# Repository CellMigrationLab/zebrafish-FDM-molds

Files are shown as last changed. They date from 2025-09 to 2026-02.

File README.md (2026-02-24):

# Customizable FDM 3D-printed zebrafish embryo molds for live imaging

---

## Introduction

This repository provides design files, printing instructions, and documentation for 3D-printed molds for orienting zebrafish embryos. The molds are designed to ensure dorsal positioning of embryos during live imaging  between 50 hours post-fertilization (hpf) and 5 days post-fertilization (dpf).

Unlike previously published molds fabricated with stereolithography (SLA)–based 3D printing (e.g., Geng & Peterson, 2021; Kleinhans & Lecaudey, 2019; Miller et al., 2025; Wittbrodt et al., 2014), our approach uses fused deposition modeling (FDM). Both SLA and FDM are part of the broader category of additive manufacturing, in which objects are built up layer by layer rather than removed from a solid block (subtractive manufacturing) or formed in a mold (injection molding).

* SLA printing relies on a laser or UV light to cure liquid resin layer by layer, producing parts with very fine resolution and smooth surfaces.
* FDM printing extrudes melted thermoplastic filament (such as PLA) through a heated nozzle to build up layers, making it widely accessible and cost-effective, but with lower resolution.

Because of these differences, SLA prints can reproduce the sharp triangular cavities of the CAD design, while FDM prints approximate them with rectangular cavities due to nozzle width (**Figure 1A** vs **1B**). Nevertheless, the molds (**Figure 2**) remain highly effective for stabilizing zebrafish embryos, while being affordable and easy to reproduce in most laboratory settings.

If you want to update the design, check the [how-to/](how-to/README.md) folder.

---

## 📂 Repository contents

* `README.md file`
* Description of tool
* How to print and assemble
* How to redesign

* `design_files/`
* `stl/` → ready-to-print STL files
* `f3d/` → Fusion 360 editable files
* `step/` → STEP files for CAD interoperability

* `printing/`
* `gcode/` → tested gcode files for 3D printers
* `slicer_profiles/` → PrusaSlicer config (.3mf / .ini)
* `printing_settings.md` → detailed printing settings

* `docs/`
* `zebrafish-molds-application-note.pdf`
* `figures/`

* `LICENSE`

---
## Figures

<p align="center">
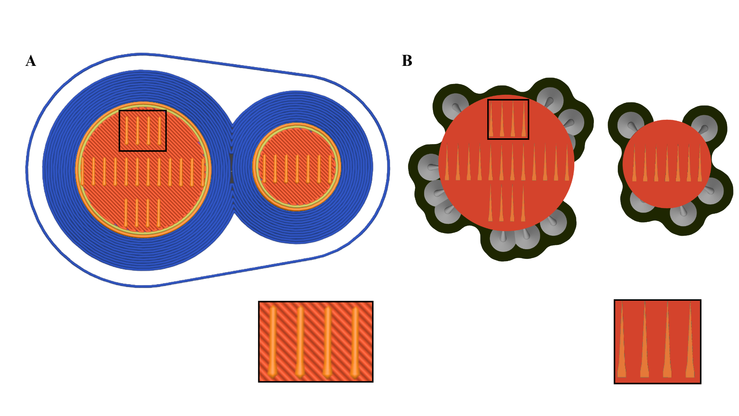
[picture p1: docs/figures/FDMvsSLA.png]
FDM vs SLA printing comparison

</p>

**Figure 1.** Differences, through g-code preview, in mold slots between FDM (**A**) and SLA (**B**) printing.

---

<p align="center">
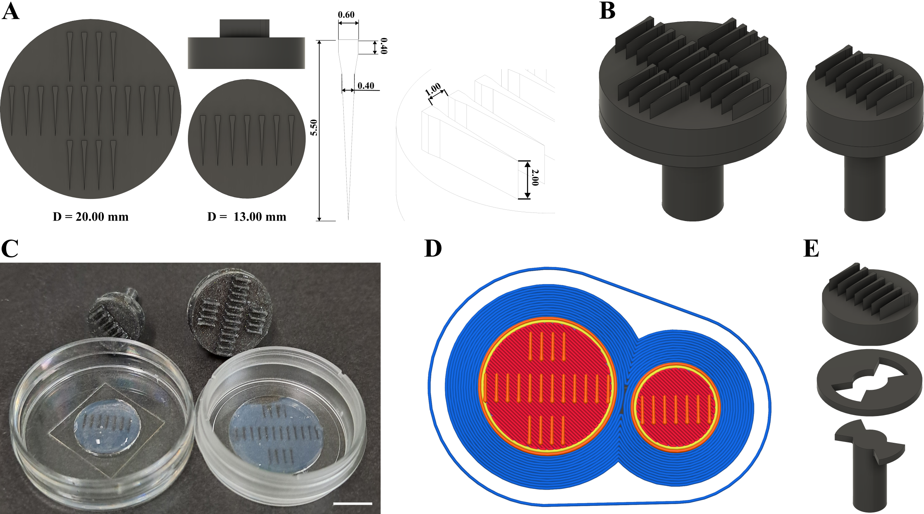
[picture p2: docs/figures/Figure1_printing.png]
Zebrafish molds 3D designs

</p>

**Figure 2.** FDM-printing-based mold design improves live in vivo imaging of brain vascularization in developing zebrafish embryos.
(**A**) CAD renderings of two circular mold sizes (20 mm and 13 mm) with slot dimensions in millimeters. Each slot measures 0.40 mm wide at the narrowest point, 0.60 mm at the widest, and extends 5.50 mm deep; the spacing between slots is 1.00 mm, and the slot height above the base is 2.00 mm. The smaller mold was designed for use with 14 mm coverslips, while the larger one was tested with 21 mm coverslips. The mold design was kept circular rather than rectangular to fit tightly within the well and stay level. Design files for both sizes are available for download via the associated GitHub repository.
(**B**) Perspective views of the assembled molds.
(**C**) Wells in 1.5% low-melting-point agarose were made using the seven- and twenty-tooth molds in 14- and 21-mm glass-bottom dishes, respectively.
(**D**) PrusaSlicer g-code preview illustrating how FDM resolution (0.4 mm nozzle) converts triangular cavities into rectangular slots.
(**E**) Exploded view of mold components, with a removable handle to facilitate positioning in small dishes.

---

<p align="center">
Zebrafish molds 3D designs
</p>

**Figure 3.** FDM-printing-based mold design enables consistent live imaging of microglia motility and brain vascularization in developing zebrafish larvae.
(**A**) Top left: image showing empty agarose wells created using the seven-teeth mold. Bottom left: image showing 56 hpf *Tg(fli1a:GFP-CAAX)*; *Tg(gata1a:DsRed)* larvae inserted into the wells. The black-dotted box indicates the area magnified in the next panel. Right: magnified area of mounted larvae. Live brightfield imaging of the middle larvae, marked with an orange box, is presented in **panel G**. Scale bars: left panels 1 mm, right panel 500 µm.
(**B**) Brightfield midplane-volume image of the 56hpf *Tg(fli1a:GFP-CAAX)*; *Tg(gata1a:DsRed)* larvae from **panel F** (orange boxed region), before the start of time-lapse acquisition, shown in **panels H-I**, orange box. Scale bar: 50 µm.
(**C**) Maximum intensity projection of horizontal sections from overnight time-lapse imaging of vasculature, *Tg(fli1a:GFP-CAAX)* (cyan), and erythrocytes, *Tg(gata1a:DsRed)* (red), in the developing brain of the mounted larvae (identical to those shown in **panels F-G**, orange box). The first timepoint is shown in **panel (i)**. Temporal color coding of the *fli1:GFP* signal over the acquisition (time-lapse, 20-minute imaging interval, 32 time points) **(ii)**. The color bar indicates the transition from time point 1 (magenta) to 32 (bright yellow). See also Movie S1. Scale bars: 50 µm.
(**D**) High-magnification (63x) imaging of the brain vascularization process. The maximum intensity projection of the first acquisition time point is shown in **(i)**. The magnified area (indicated with an orange rectangle) shows filopodia-like protrusions extending from the *fli1:GFP*-positive (cyan) endothelial tip cell **(ii)**. The *gata1a:DsRed* positive erythrocytes (red) inside a more mature blood vessel are also shown. See also Movie S1. Scale bars: 25 µm and 5 µm, respectively.
(**E**) Temporal color coding of microglia dynamics in *Tg(mpeg1.1:GFP-CAAX)* 72 hpf larvae, over the acquisition period (10-minute imaging interval, 80 time points). The color bar indicates the transition from time point 1 (magenta) to 80 (bright yellow). Scale bar: 50 µm.
(**F**) Selected time-points from **panel E** (blue box),  showing microglia *Tg(mpeg1:GFP-CAAX)* (grey) migration and process elongation. Scale bar: 20 µm.

---

<p align="center">
Supplementary movie
</p>

**Supplementary Movie S1.** Movie S1. Brain vascularization in the developing brain of a mounted larva. Development of brain vasculature and erythrocyte flow in more mature vessels was imaged in larvae expressing both *Tg(fli1a:GFP-CAAX)* (cyan) and *Tg(gata1a:DsRed)* (red) reporters. For **parts A** and **B**, the time intervals are 20 and 2 minutes, and the scale bars are 40 µm and 20 µm, respectively. For **part A**, acquisition was started at 54 hpf, and for **part B**, at 68 hpf (in the same larvae).

---

<p align="center">
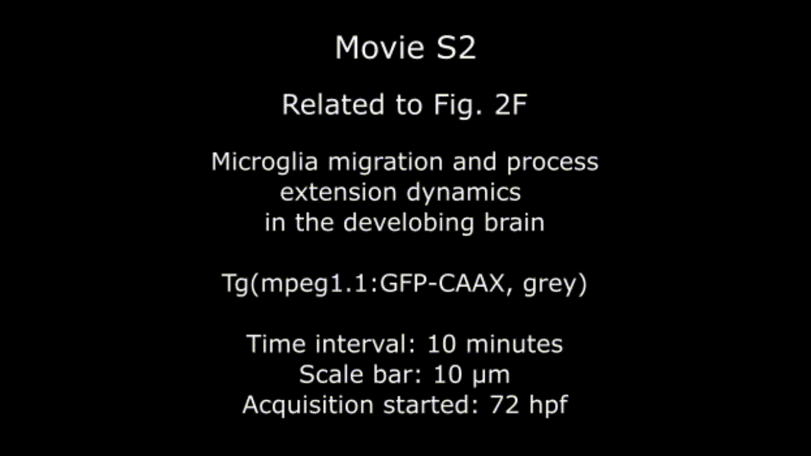
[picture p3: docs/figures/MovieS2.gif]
Supplementary movie

</p>

**Supplementary Movie S2.** Microglia migration and process extension dynamics in the developing brain of a mounted larva. Single microglia migration and elongation and retraction of its processes, labelled by *Tg(fmpeg1.1:GFP-CAAX)* (grey) reporter, was imaged for 12 hours. Time interval 10 minutes. Acquisition started at 72 hpf.  Scale bar 10  µm.

---

## 🔍 Design considerations

* **Circular footprint**: Chosen to fit tightly into 14 mm and 21 mm coverslip dishes.
* **FDM vs SLA**: FDM printing with a 0.4 mm nozzle limits precision, resulting in rectangular cavities instead of sharp triangular ones. Functionality is unaffected, but geometric fidelity is reduced.
* **Stage compatibility**: Optimized for zebrafish between 50 hpf–5 dpf.
* **Accessibility**: All files are openly shared for reproduction and adaptation.

⚠️ **Note:** Embryos younger than 50 hpf are too small for this design. Separate molds with smaller wells would be required. (see the [how-to/](how-to/README.md) folder).

## 📚 References

* Geng, Y., & Peterson, R. T. (2021). Rapid Mounting of Zebrafish Larvae for Brain Imaging. Zebrafish, 18(6), 376. https://doi.org/10.1089/zeb.2021.0062
* Kleinhans, D. S., & Lecaudey, V. (2019). Standardized mounting method of (zebrafish) embryos using a 3D-printed stamp for high-content, semi-automated confocal imaging. BMC Biotechnology, 19(1), 68. https://doi.org/10.1186/s12896-019-0558-y
* Miller, J. C., Koirala, P., Torre, M. F. A. de la, Farsi, M., Lieberth, J., Shrestha, R., & Bloomekatz, J. (2025). Custom 3D-Printed Molds for Zebrafish Imaging and Cardiac Development. Journal of Visualized Experiments (JoVE), 222, e68768. https://doi.org/10.3791/68768
* Wittbrodt, J. N., Liebel, U., & Gehrig, J. (2014). Generation of orientation tools for automated zebrafish screening assays using desktop 3D printing. BMC Biotechnology, 14(1), 36. https://doi.org/10.1186/1472-6750-14-36

---

## 📖 Citation

If you use these zebrafish molds in your research, please cite:

**Customizable FDM-based zebrafish embryo mold for live imaging** Rivera Pineda MX, Lehtimäki J, Jacquemet G.

*bioRxiv* (2025)
[](https://doi.org/10.1101/2025.11.24.689779)

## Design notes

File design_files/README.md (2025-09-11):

# Design files for zebrafish embryo molds

This directory contains all CAD and related files for the FDM-printed zebrafish embryo orientation molds.  
Different file formats are provided to support a range of use cases, from direct printing to full CAD editing.

## 📂 Subfolders
- **`stl/`** → Ready-to-print mesh files for 3D printing.  
- **`f3d/`** → Editable Fusion 360 project files with parametric history.  
- **`step/`** → Cross-CAD geometry files for SolidWorks, FreeCAD, Onshape, etc.  
- **`drawings/`** → 2D technical drawings with dimensions and component breakdowns.

## 🛠 Choosing the right file
- Use .stl if you just want to slice and print.  
- Use .f3d if you want to make design modifications in Fusion 360.  
- Use .step if you need to work in a different CAD program.  
- Use drawings if you only need dimensions or want to check geometry without CAD software.

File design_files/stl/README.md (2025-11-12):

# STL Files (`.stl`)

This folder contains the STL files for the zebrafish embryo molds. STL files describe the mesh geometry of the model and are the most common format for 3D printing. 

## Files
- **`zfish-mold-stamp/stemlock/stem-D13.stl`** → Mold with 13 mm diameter, designed for 14 mm coverslip plates.  
- **`zfish-mold-stamp/stemlock/stem-D20.stl`** → Mold with 20 mm diameter, tested with 21 mm coverslip plates.  

## Notes
- STL files are ready-to-slice in PrusaSlicer, Cura, or other slicers.  
- Unlike `.f3d` or `.step` files, STLs do not include parametric history or editable sketches. They are mesh-only files intended for printing.  
- To modify geometry (e.g., slot width, spacing, or mold diameter), use the editable `.f3d` (Fusion 360) or `.step` files instead.  
- Both STL versions share the same slot dimensions:  
  - Slot depth: **5.50 mm**  
  - Narrow width: **0.40 mm**  
  - Wide width: **0.60 mm**  
  - Slot spacing: **1.00 mm**  
  - Slot height above base: **2.00 mm**  

## Recommended workflow
1. Choose the STL that matches your imaging dish (13 mm or 20 mm).  
2. Open in PrusaSlicer (or another slicer).  
3. Apply the provided print settings (`printing/printing_settings.md` or `.ini`/`.3mf` profile).  
4. Export G-code and print.

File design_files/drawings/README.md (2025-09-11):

# Technical drawings

This folder contains 2D technical drawings of the zebrafish embryo molds. These provide a quick reference for dimensions and part relationships without requiring CAD software.

## Files
- **`zfish-mold-D13_drawing.pdf`** → Drawing of the 13 mm mold (for 14 mm coverslip plates).  
- **`zfish-mold-D20_drawing.pdf`** → Drawing of the 20 mm mold (for 21 mm coverslip plates).  

## Contents
Each drawing includes:
- Overall mold dimensions (diameter, height, slot spacing).  
- Individual component views:  
  - Stamp (slot pattern and depth).  
  - Stemlock (circular locking ring).  
  - Stem (removable handle).  
- Exploded views of how components fit together.   

## Notes
- Scale in drawings: 3:1  
- Units: millimeters (mm)  
- If modifications are desired, consult the `.f3d` or `.step` files in their respective folders.

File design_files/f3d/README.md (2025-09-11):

# Fusion 360 source files (`.f3d`)

This folder contains the editable Fusion 360 project files for the zebrafish embryo molds. These preserve the parametric history, allowing users to modify slot dimensions, mold diameter, or handle design directly in Fusion 360.

## Files
- **`zfish-mold-D13.f3d`** → Mold with 13 mm diameter, designed for 14 mm coverslip plates.  
- **`zfish-mold-D20.f3d`** → Mold with 20 mm diameter, tested with 21 mm coverslip plates.  

## Dimensions (shared by both designs)
- Slot depth: **5.50 mm**  
- Slot narrow width: **0.40 mm**  
- Slot wide width: **0.60 mm**  
- Slot spacing: **1.00 mm**  
- Slot height above base: **2.00 mm**  

## Notes
- Files open in Autodesk Fusion 360 (educational or commercial license).  
- The design is structured into components (stamp:mold; stemlock:base; stem:handle) for easier editing.  
- Use these if you wish to customize geometry (e.g., for different embryo stages or dish sizes).

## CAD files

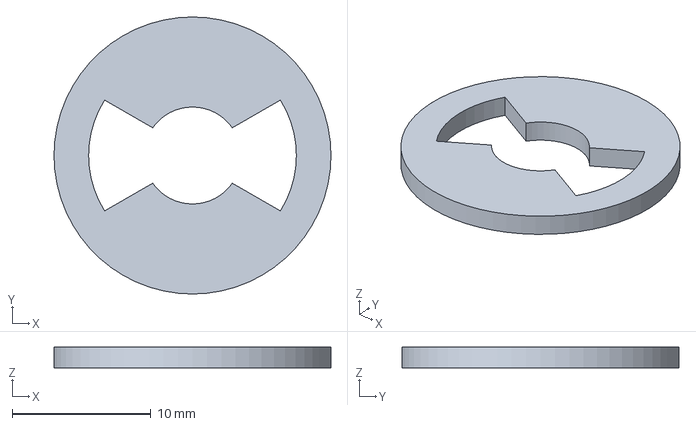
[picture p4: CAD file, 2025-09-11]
design_files/step/zfish-mold-stemlock-D20.step
20.0 x 20.0 x 1.50 mm

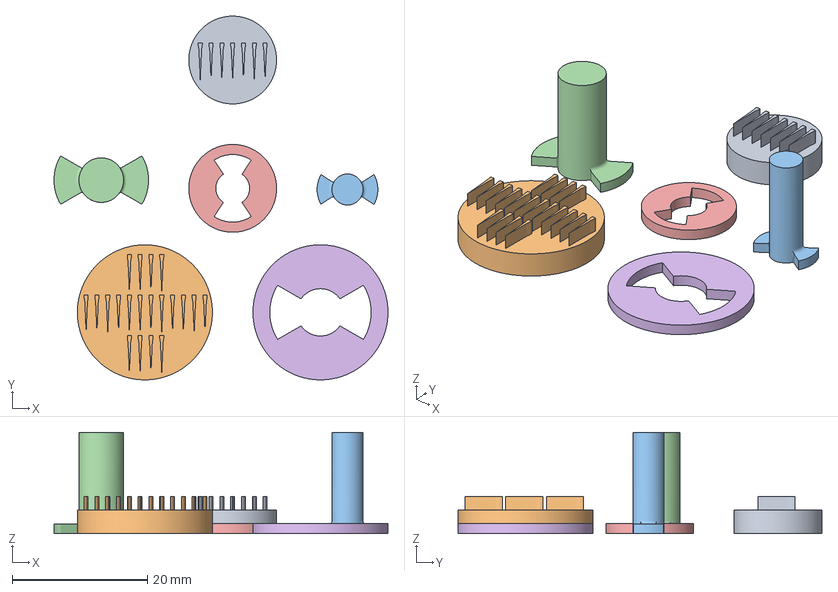
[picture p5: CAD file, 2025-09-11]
printing/slicer_profiles/zfish-molds-print-settings.3mf
49.5 x 53.9 x 15.0 mm
zfish-mold-stamp-D13
zfish-mold-stamp-D20
zfish-mold-stem-D13
zfish-mold-stem-D20
zfish-mold-stemlock-D13
zfish-mold-stemlock-D20

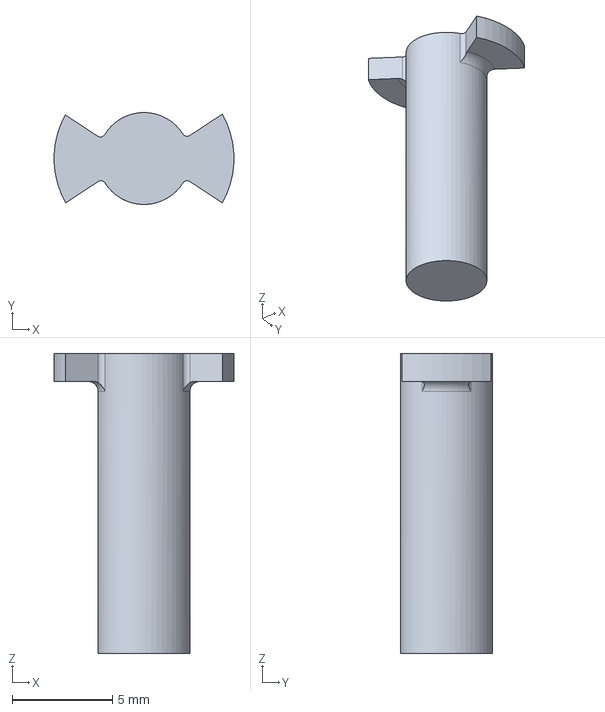
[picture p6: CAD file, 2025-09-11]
design_files/step/zfish-mold-stem-D13.step
8.99 x 4.60 x 15.0 mm

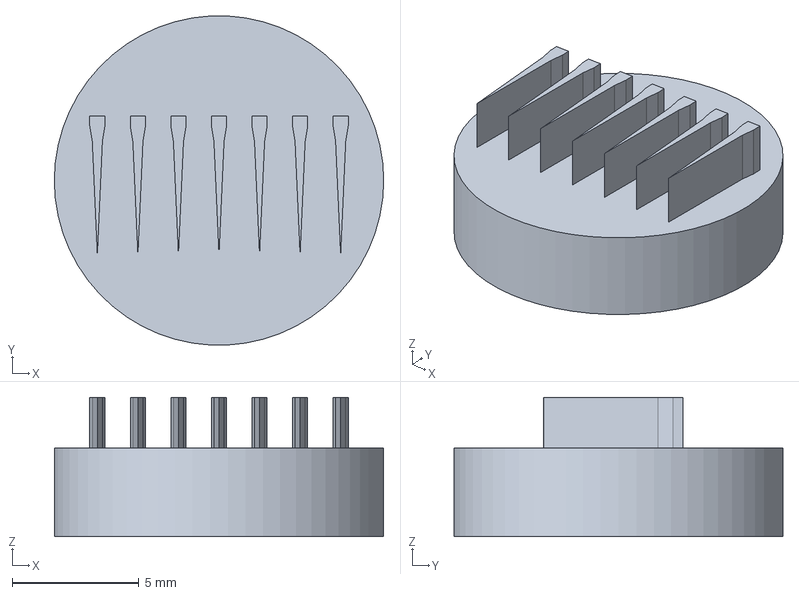
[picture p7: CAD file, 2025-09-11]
design_files/step/zfish-mold-stamp-D13.step
13.0 x 13.0 x 5.50 mm

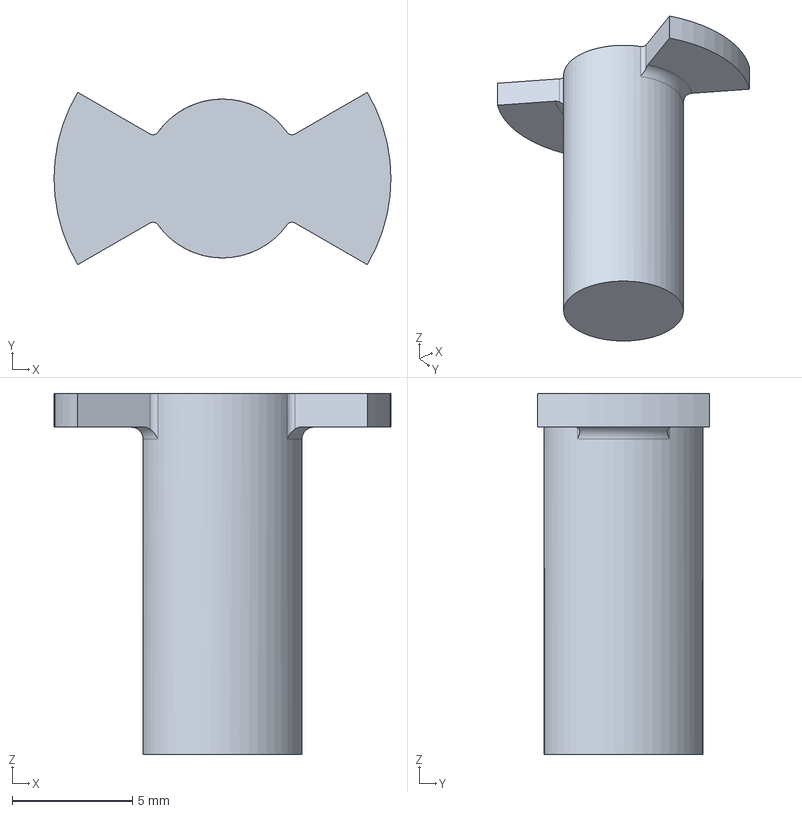
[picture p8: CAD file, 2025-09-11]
design_files/step/zfish-mold-stem-D20.step
14.0 x 7.16 x 15.0 mm

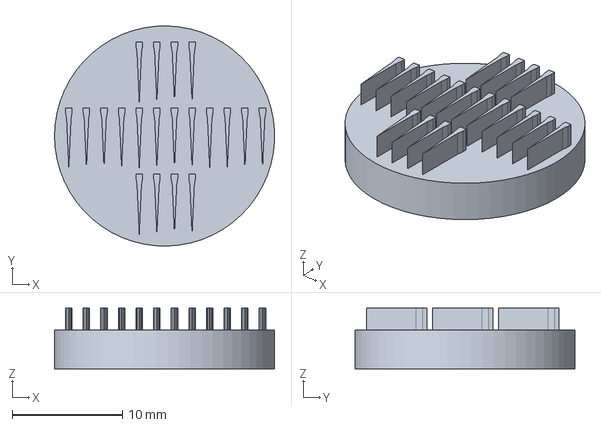
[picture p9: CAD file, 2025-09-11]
design_files/step/zfish-mold-stamp-D20.step
20.0 x 20.0 x 5.50 mm

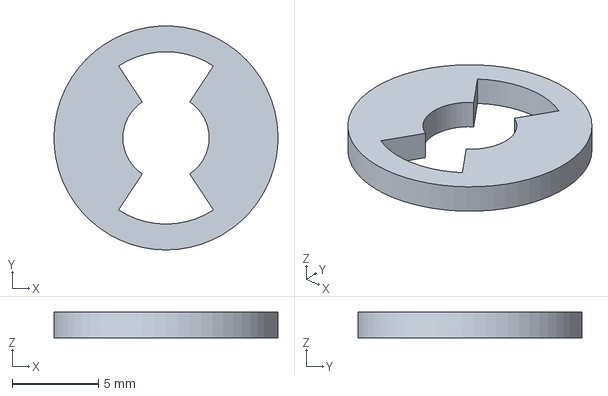
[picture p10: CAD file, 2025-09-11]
design_files/step/zfish-mold-stemlock-D13.step
13.0 x 13.0 x 1.50 mm

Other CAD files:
design_files/f3d/zfish-mold-D13.f3d
design_files/f3d/zfish-mold-D20.f3d
design_files/stl/zfish-mold-stamp-D13.stl
design_files/stl/zfish-mold-stamp-D20.stl
design_files/stl/zfish-mold-stem-D13.stl
design_files/stl/zfish-mold-stem-D20.stl
design_files/stl/zfish-mold-stemlock-D13.stl
design_files/stl/zfish-mold-stemlock-D20.stl

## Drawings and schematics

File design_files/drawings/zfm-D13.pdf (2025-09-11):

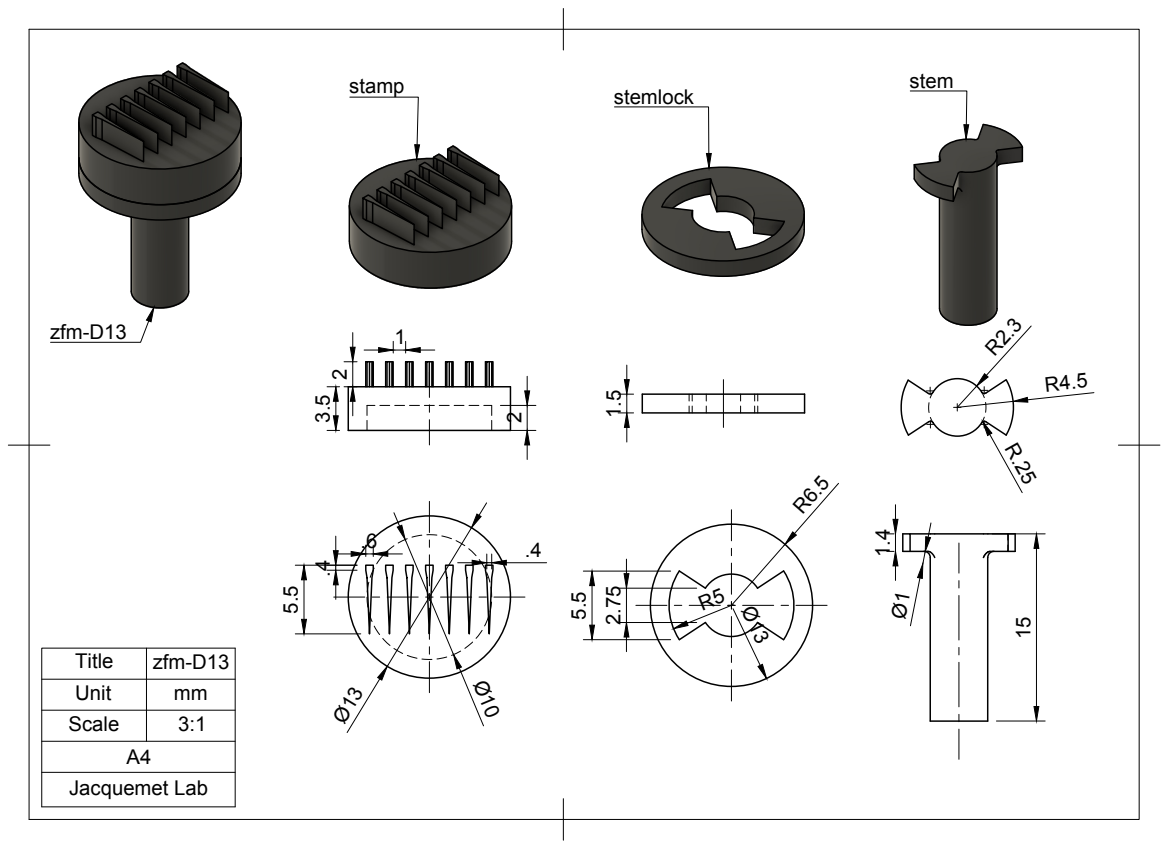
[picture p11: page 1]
Jacquemet Lab

Title | zfm-D13
Unit | mm
Scale | 3:1

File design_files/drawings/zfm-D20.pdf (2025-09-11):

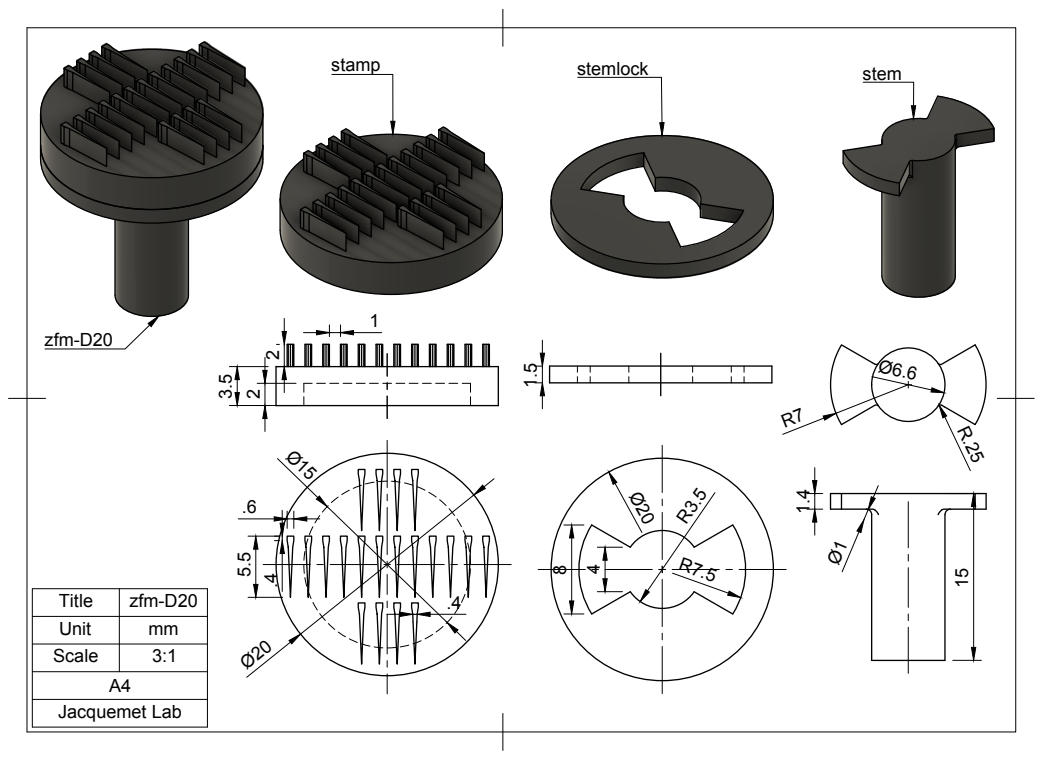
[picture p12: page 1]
Jacquemet Lab; stamp; stemlock; stem 3.5 2

Unit | mm
Scale | 3:1

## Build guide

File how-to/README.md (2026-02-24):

# How-to guides

This directory contains how-to guides related to the FDM-printed zebrafish embryo orientation molds.  

## 📂 Content
- **how-to 1: redesign the wells** → Modify the molds according to the developmental stage of your zebrafish embryos/larvae.
- **how-to 2: print and assemble** → Print and assemble your molds.

## How-to 1: Redesign the wells

***Note 1:*** Changing one dimension of the first well propagates to the others. Therefore, after edits, you should always check for overlapping and spacing. 
***Note 2:*** These steps can be implemented to modify other dimensions of the mold, such as the depth of the wells or the diameter of the mold.
***Note 3:*** All redesign steps were performed in Autodesk Fusion 360. Although Fusion 360 is subscription-based, a free educational license is available for academic users.

Steps:
1. Open the corresponding mold file (.f3d file) in Fusion 360. Open the wells sketch by double-clicking the first sketch in the Timeline (highlighted by the red rectangle in Figure 3A).
2. Modify well dimensions by double-clicking the desired dimension as shown in Figure 3B (red rectangle). Edit the relevant dimensions (head width, neck width, length) according to the embryo/larva stage. See Figure 3E for suggested dimensions based on embryo stage (based on Kimmel et al. (1995)).
3. After resizing the wells, check the dimensions regarding the distance between the first well and the edge reference. Update it so the modified wells still fit cleanly within the diameter boundary. E.g.: 1.4 mm (Figure 3B, red triangle) to 1.2 mm (Figure 3C, red triangle) after changing the well geometry.
4. Verify spacing and pattern integrity by ensuring that the wells don’t overlap after the update. If the wells overlap, modify the spacing by zooming in, double-clicking the Rectangular Pattern Constraint (dotted rectangle in Figure 3D), and adjusting the number of wells (green triangle in Figure 3D) and the distance between them (magenta triangle in Figure 3D).
5. Click Finish Sketch. In the Timeline, confirm that the extrude and cut features regenerated correctly.
6. Export the updated mold as an STL file and proceed to slicing and 3D printing. To export, go to File> Export…, and change the Type to STL Files (*.stl).

<p align="center">
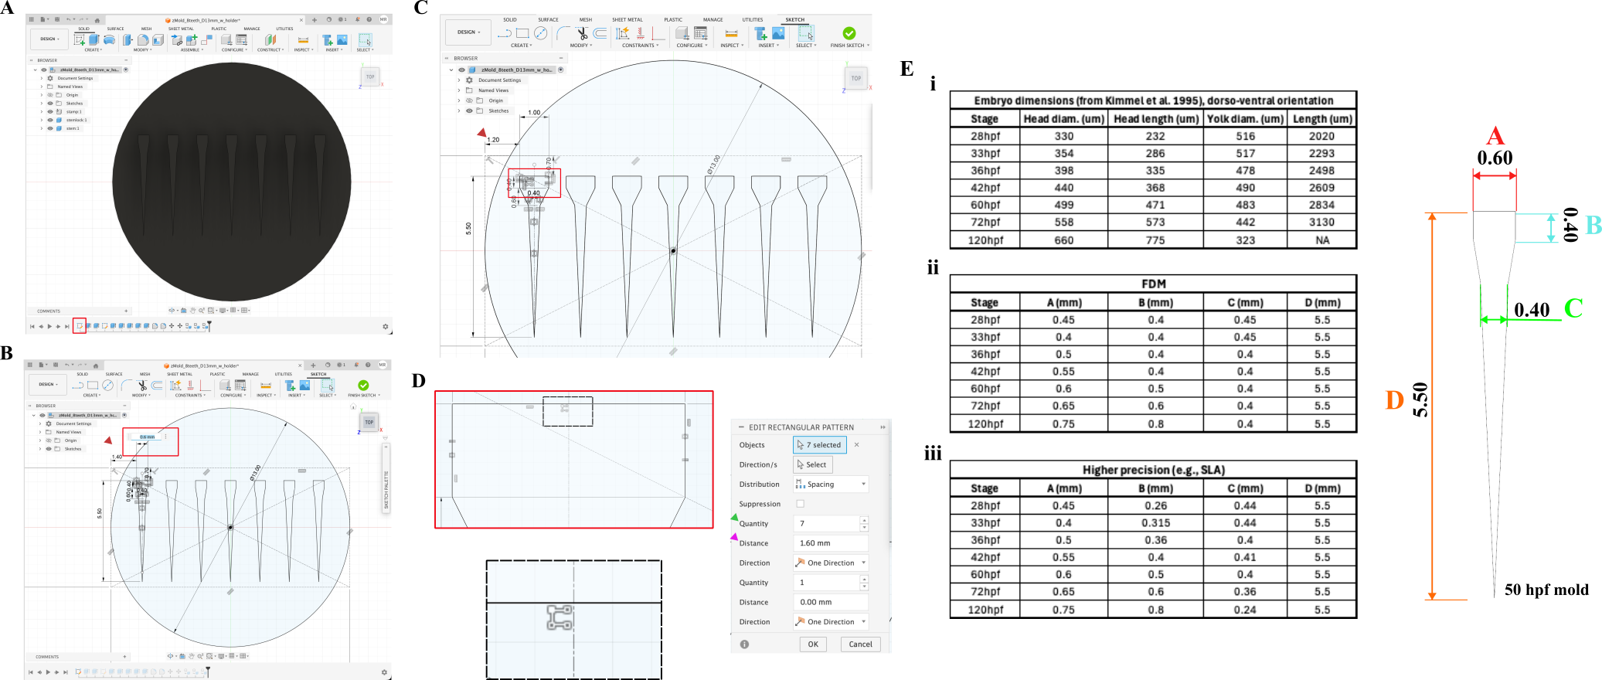
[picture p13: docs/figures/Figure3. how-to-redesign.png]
how to redesign the zebrafish molds

</p>

**Figure 1.** How to redesign the zebrafish molds. 
(**A**) Autodesk Fusion 360 project file showing the mold with replicated wells arranged to fit a standard glass-bottom imaging dish. The red rectangle highlights the sketch to edit to modify the wells’ dimensions.
(**B**–**C**) The well sketch can be edited by opening the first sketch in the Timeline and modifying the parameterized dimensions (example shown for the first well; red rectangle). After resizing, the offset between the first well and the dish boundary should be updated to ensure the pattern remains within the circular mold footprint (red triangle). 
(**D**) If resizing causes wells to overlap, spacing and/or the number of wells can be adjusted using the Rectangular Pattern Constraint (dotted black rectangle). 
(**E**) Suggested stage-dependent dimensions to guide redesign: (**E**, i) embryo measurements (dorso-ventral orientation) extracted from Kimmel et al. (1995); (**E**, ii) corresponding recommended well parameters for FDM printing; (**E**, iii) corresponding parameters for higher-precision printing (e.g., SLA). Right: schematic of the well geometry indicating the editable parameters **A**-**D** (mm) used throughout the tables.

---

## 🖨 How-to 2: Printing and assembly instructions

1. Download STL files from `design_files/stl/`.
2. Open in PrusaSlicer (or your slicer of choice).  
   - Recommended settings are included in `printing/printing_settings.md`.
3. Print using PLA material with a 0.4 mm nozzle.  
4. ⚠️ Critical step.  To minimize adhesion to the agarose gel, sand the printed molds carefully but roughly. This will increase surface porosity for resin infiltration (next step). 
5. Apply a thin coat of two-part epoxy over all surfaces of the mold that contact the agarose gel to create a smooth, sealed surface. Allow to cure fully before use (24h or as required by the manufacturer).
6. The stamp component is glued to the middle ring, forming a single object and creating an internal pocket. 
7. The stem is inserted into this pocket and rotated ~180° to lock or unlock its position. Once assembled, the mold is ready for use.

<p align="center">
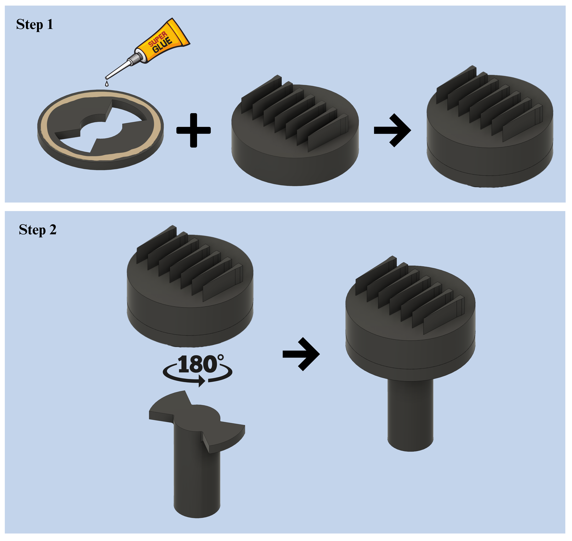
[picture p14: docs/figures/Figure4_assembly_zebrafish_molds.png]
zebrafish mold assembly steps

</p>

**Figure 2.** Assembly of the zebrafish molds.

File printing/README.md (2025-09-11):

### 🖨 Profiles and settings

This repository provides multiple ways to reproduce the validated printing parameters:

- **`printing_settings.md`** → A human-readable summary of all printing settings (layer height, infill, speeds, cooling, supports, etc.). These values can be entered manually into any slicer (e.g., Cura, Simplify3D, etc.).  
- **`zfish-molds-print-settings.ini`** → A PrusaSlicer-specific profile. This format is inherent to PrusaSlicer and may not be directly compatible with other slicers.  
- **`zfish-molds-print-settings.3mf`** → A PrusaSlicer project profile that can be dragged and dropped into PrusaSlicer for one-click setup.

👉 If you are **not using PrusaSlicer**, refer to `printing_settings.md` for the full parameter set.

👉 May require adjustment for other printers/materials.

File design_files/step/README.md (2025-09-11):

# STEP files (`.step`)

This folder contains STEP versions of the zebrafish embryo mold designs. STEP is a widely supported neutral CAD format and can be imported into software such as SolidWorks, FreeCAD, Onshape, Rhino, or CATIA.

## Files
- **`zfish-mold-stamp/stemlock/stem-D13.step`** → Mold with 13 mm diameter, designed for 14 mm coverslip plates.  
- **`zfish-mold-stamp/stemlock/stem-D20.step`** → Mold with 20 mm diameter, tested with 21 mm coverslip plates.  

## Notes
- STEP files preserve geometry, but do not include the parametric history or design tree from Fusion 360.  
- Best used if you want to view or adapt the model in a non-Fusion CAD environment.  
- For fully editable parametric designs, use the `.f3d` files in the `f3d/` folder.

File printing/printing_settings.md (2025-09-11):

# Printing settings for zebrafish molds

These settings were generated and validated in PrusaSlicer 2.8.1 for an Original Prusa i3 MK3S/MK3S+ printer using Prusament PLA (1.75 mm, Jet Black). May require adjustment for other printers/materials.

---

## General
- **Printer technology:** FDM (FFF)
- **Printer model:** Prusa i3 MK3S/MK3S+
- **Nozzle diameter:** 0.4 mm
- **Layer height:** 0.10 mm (high-detail setting)
- **Extrusion width:** 0.45 mm

---

## Temperatures
- **Nozzle temperature:** 215 °C (first layer and subsequent layers)
- **Bed temperature:** 60 °C (first layer and subsequent layers)

---

## Speeds
- **Perimeters:** 30 mm/s  
- **External perimeters:** 15 mm/s  
- **Small perimeters:** 15 mm/s  
- **Infill:** 60 mm/s  
- **Solid infill:** 80 mm/s  
- **Top solid infill:** 40 mm/s  
- **Bridges:** 25 mm/s  
- **First layer:** 20 mm/s  

---

## Perimeters & shell
- **Perimeters:** 2  
- **Top solid layers:** 8  
- **Bottom solid layers:** 5  
- **Seam position:** Aligned  

---

## Infill
- **Density:** 5%  
- **Pattern:** Gyroid  
- **Overlap:** 25%  

---

## Supports
- **Style:** Organic supports  
- **Pattern:** Honeycomb  
- **Threshold angle:** 50°  
- **Contact distance:** 0.2 mm  
- **Interface layers:** 2  
- **Speed:** 50 mm/s  

---

## Cooling
- **Fan:** 100% after layer 4  
- **Disable fan on first layers:** Yes (first 3 layers)  

---

## Retraction
- **Length:** 0.8 mm  
- **Lift (Z-hop):** 0.4 mm  
- **Speed:** 35 mm/s  

---

## Adhesion
- **Brim:** Enabled (5 mm width, outer only)  
- **Skirt:** 1 loop, 2 mm distance  

---

## Post-processing
- After printing, sand the molds to remove roughness.  
- Apply a thin coat of two-part epoxy and allow to cure for 24 h before use.  

---

## Notes
- These settings prioritize surface quality and fine detail for the narrow mold slots.  
- Printing at 0.10 mm layer height ensures sharper cavity edges, though it increases print time.  
- 100% infill can be used if extra rigidity is desired, but 5% gyroid with multiple perimeters was sufficient in our tests.

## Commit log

2025-09-10 Upload stl files.
    [zfish-mold-stamp-D13.stl, zfish-mold-stamp-D20.stl, zfish-mold-stem-D13.stl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]
2025-09-11 Upload zfish-molds-print-settings.3mf
    [zfish-molds-print-settings.3mf]
2025-09-11 Upload zfish-molds-print-settings.ini
2025-09-11 Upload printingzfish-molds-D13-D20.gcode
2025-09-11 Upload zfish-molds-D13-D20.gcode
2026-02-24 Update README with figures and descriptions
    Added images and descriptions for FDM vs SLA printing comparison and zebrafish mold designs.
